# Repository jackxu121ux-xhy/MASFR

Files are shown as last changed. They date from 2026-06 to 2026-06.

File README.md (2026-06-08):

# MASFR: Multimodal Adhesion, Sliding, and Flying Robot

This repository collects replication materials for MASFR, a bioinspired multimodal robot that combines aerial flight with adhesion-assisted surface crawling. MASFR uses distributed micro-setae suction feet inspired by net-winged midge larvae, pressure-regulated adhesion-sliding gaits, and a multi-weighted probabilistic roadmap planner (MW-PRM) for structured multimodal path generation.

The repository is organized to support manuscript review and replication. It includes the MW-PRM planner code and example point-cloud scenes, ROS 2 control software, STM32 crawler firmware, figure-level raw data, representative CAD/STL/STEP files, and an annotated video of successful and representative failed slope-perching trials.

## Manuscript Summary

Flying-perching robots can save energy by attaching to surfaces, but many existing systems must repeatedly take off, realign, and perch when they need to change position after landing. MASFR addresses this limitation by combining flight with controllable adhesion-sliding on surfaces.

The robot is built around four articulated adhesion-sliding legs mounted on a quadrotor platform. Each leg uses a Distributed Micro-setae Sucker (DMS), whose pressure-regulated contact state can switch between high-adhesion and low-friction sliding. In the manuscript experiments, the DMS provides a friction modulation ratio of 407.5%, reducing wet-state shear stress from 21.6 kPa in adhesion mode to 5.3 kPa in sliding mode. The robot demonstrates forward, lateral, and turning gaits through alternating adhesion and sliding phases.

MASFR also includes a lightweight closed-loop crawling controller that uses heading and lateral path errors to generate turning and forward commands for surface trajectory tracking. In robot-level tests, MASFR crawled on a 40 degree inclined surface against 1.5 m/s flow while carrying a 2 kg payload. The reported climbing power consumption was 21.7 W, about 2.3% of flight power under the tested condition.

For mission-level autonomy in known or pre-mapped environments, the project uses MW-PRM. The planner samples aerial, ground, and adhesive-surface nodes from geometric or point-cloud maps, constructs feasible flight, crawling, and adhesive-surface edges, and runs weighted A* over a hybrid graph. The cost model balances energy, traversal time, and mode-switching penalties. Indoor experiments show optimized multimodal trajectories that reduce energy consumption by 31.7% and improve positioning precision by 58.5% compared with single-mode flight.

Outdoor demonstrations on frozen lakeshores, rough pavement, inclined glass roofs, and narrow beam structures validate mechanical feasibility and environmental adaptability. These outdoor tests were pilot-controlled demonstrations rather than online SLAM-based autonomous navigation.

## Repository Layout

```text
MASFR/
|-- algorithms/
|   `-- mw_prm/                         # MW-PRM planner code and examples
|-- cad/                                # CAD, STL, and STEP geometry
|   |-- Crawling System/
|   |-- DMS_sucker/
|   `-- Leg_Module/
|-- multimodal control/                 # ROS 2 control stack and embedded crawling firmware
|   |-- crawling/
|   |   `-- program_stm/                # STM32 crawler control-board firmware
|   `-- masfr_ros2_ws/                  # ROS 2 workspace for MASFR execution
|-- raw data/                           # Figure-level Excel source data
|   |-- Fig.3/
|   |-- Fig.5/
|   `-- Fig.7/
`-- videos/
    `-- Successful and Failed Cases of Slope Perchings .mp4
```

## MW-PRM Algorithm Module

The planner code is provided in `algorithms/mw_prm/`. It supports two environment backends:

- analytic obstacle scenes from Python parameter files;
- point-cloud scenes from `.pcd` or `.ply` files using Open3D, KD-tree collision checking, and 2.5D height-map constraints.

The planner builds a multimodal graph with ground/surface crawling nodes and aerial nodes. Edges are assigned locomotion-mode costs and switching penalties, then searched with A* to produce mode-labeled paths.

### Environment Setup

From the repository root:

```bash
cd algorithms/mw_prm
conda env create -f environment.yml
conda activate mmprm
```

If Conda is unavailable, use Python 3.9+ and install the scientific stack manually. On Python 3.12, `open3d==0.18.0` may not provide wheels on Windows; `open3d==0.19.0` was used successfully for the local smoke test.

### Smoke Test

```bash
cd algorithms/mw_prm
python main_pcd.py --yml yml/pcd/synth_parameters_obstacles.yml --no-vis
```

A successful run loads the synthetic point cloud, samples PRM nodes, connects feasible edges, runs multimodal A*, reports path waypoints and path length, then exits without opening the Open3D viewer because `--no-vis` is enabled.

## ROS 2 Control Software And STM32 Firmware

The execution software is organized under `multimodal control/`.

- `multimodal control/masfr_ros2_ws/` is the MASFR ROS 2 workspace. It contains packages for PX4 offboard control, crawler serial control, TCP motion-capture input, VINS-compatible camera/IMU bridging, launch orchestration, and multimodal mission coordination.
- `multimodal control/crawling/program_stm/` contains the STM32F405 firmware for the crawler control board. It receives serial command packets from the ROS 2 crawling client and drives the solenoid valves, pump output, servo/actuator initialization, and staged gait routines.
- `multimodal control/crawling/` contains crawling-control notes and embedded firmware materials for adhesion-sliding locomotion.

Because the control directory name contains a space, quote it in shell commands:

```bash
cd "multimodal control/masfr_ros2_ws"
source /opt/ros/<ros2-distro>/setup.bash
colcon build --symlink-install
```

## CAD, Raw Data, And Videos

The repository includes releasable supporting materials:

- `cad/` contains STEP/STL files for the crawling system layout, DMS sucker parts, and front/hind leg modules.
- `raw data/` contains Excel source data for Fig.3, Fig.5, and Fig.7.
- `videos/` contains the annotated slope-perching success and failure case video.

See the README files in each directory for file-level indexes.

## Data and Materials Availability

The manuscript states that the main data are available in the main text or supplementary materials. This repository includes source data tables supporting the reported adhesion, friction, locomotion, and multimodal robot-level results, organized by manuscript figure.

The repository also includes control software, STM32 crawler firmware, representative CAD/STL/STEP files, and an annotated video of successful and representative failed slope-perching trials. Additional hardware files may be made available from the corresponding authors upon reasonable request.

## Current Scope and Limitations

The included MW-PRM implementation assumes known or pre-mapped static environments and generates mode-labeled trajectories before execution. It does not yet implement online SLAM or dynamic global replanning. The suction system described in the manuscript currently uses calibrated open-loop pressure regulation; embedded pressure or tactile feedback is a planned extension. Dynamic perching tests in the manuscript showed reliable landing on planar inclined acrylic surfaces up to about 40 degrees under the tested landing conditions.

## Citation

Citation information will be added after publication or preprint release. For questions about the manuscript or hardware materials, please contact the corresponding authors listed in the manuscript.

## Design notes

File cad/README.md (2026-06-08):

# CAD and Design Files

This directory contains releasable CAD, STL, and STEP geometry for the MASFR hardware.

## Contents

- `Crawling System/Crawling System Layout.STEP` - assembly-level crawling system layout.
- `DMS_sucker/DMS Sucker - Distributed micro spines.STL` - distributed micro-spine component for the DMS sucker.
- `DMS_sucker/DMS Sucker - Main body.STL` - main DMS sucker body.
- `DMS_sucker/DMS Sucker - Soft holder.STL` - soft holder component.
- `DMS_sucker/DMS Sucker - Soft Lips.STL` - soft lip component.
- `Leg_Module/Front Leg.STEP` - front leg module geometry.
- `Leg_Module/Hind Leg.STEP` - hind leg module geometry.

## Notes

File names are kept descriptive so that manuscript readers can identify the crawling layout, DMS sucker parts, and leg-module CAD without additional lookup tables. Check dimensions and manufacturing tolerances before using these files for fabrication.

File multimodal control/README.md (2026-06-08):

# Multimodal Control

This directory collects the MASFR execution software and embedded crawling firmware.

## Contents

- `masfr_ros2_ws/` - ROS 2 workspace for PX4 offboard control, crawler serial control, motion-capture feedback, VINS sensor bridging, launch orchestration, and multimodal mission coordination.
- `crawling/program_stm/` - STM32F405 firmware for the crawler control board. It receives serial packets from the ROS 2 crawling client and drives actuator, solenoid, pump, initialization, and gait logic.
- `crawling/README.md` - crawling-control index and hardware safety notes.

## Usage Notes

The ROS 2 workspace keeps the high-level execution nodes. The STM32 firmware in `crawling/program_stm/` provides the low-level actuator, solenoid, pump, and gait logic used by the crawler. The two layers communicate through the serial protocol documented in the `robot_crawl` and `program_stm` README files.

Because this path contains a space, shell examples should quote it:

```bash
cd "multimodal control/masfr_ros2_ws"
```

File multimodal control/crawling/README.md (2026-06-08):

# Crawling Control

This directory contains MASFR crawling-control materials for adhesion-sliding locomotion.

## Contents

- `program_stm/` - STM32F405 firmware for the crawler control board. It receives serial commands, drives solenoid valves and pump outputs, and executes staged gait routines.
- Parameter and notes files may be added here for gait timing tables, pressure/vacuum timing, servo command settings, and trajectory-tracking gains.

## ROS 2 Integration

The high-level ROS 2 crawler package lives in `../masfr_ros2_ws/src/robot_crawl/`. It sends packed serial commands to the STM32 firmware over the configured serial device, typically `/dev/ttyAMA1` at 115200 baud.

The multimodal mission package in `../masfr_ros2_ws/src/multimodal_motion/` can also dispatch crawling segments using motion-capture feedback and the same serial command format.

Before running on hardware, verify the serial device path, actuator wiring, pump/valve mapping, and emergency stop procedure.

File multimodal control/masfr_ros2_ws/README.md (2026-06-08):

# MASFR ROS 2 Workspace

This workspace contains the ROS 2 software used to run and integrate MASFR flight, adhesion-sliding crawling, motion-capture feedback, visual-inertial sensor bridging, and multimodal mission execution.

The ROS 2 package names and executable names are preserved from the source code. The workspace directory was renamed from the uploaded project name to `masfr_ros2_ws` so that the repository layout reflects the MASFR control stack.

## Layout

- `src/` - ROS 2 packages and external PX4/VRPN dependencies.
- `build/`, `install/`, and `log/` - generated by `colcon build` and not required as source files.

## MASFR Packages

- [multimodal_motion](src/multimodal_motion/README.md) - mission coordinator for alternating flight and crawling segments, including `manipulation`, `node_crawling`, and `node_px4`.
- [robot_crawl](src/robot_crawl/Readme.md) - crawler teleoperation and motion-capture-based trajectory following. It sends serial packets to the STM32 crawling firmware under `../crawling/program_stm/`.
- [px4_offboard_control](src/px4_offboard_control/README.md) - PX4 offboard control examples and mission execution with optional serial coordination.
- [mocap_receiver](src/mocap_receiver/README.md) - TCP motion-capture receiver that republishes pose data to ROS 2 and PX4-compatible odometry topics.
- [sensor_to_vins](src/sensor_to_vins/README.md) - stereo image and PX4 IMU bridge for VINS-compatible topics.
- [launch_file](src/launch_file/README.md) - launch descriptions for starting the multimodal motion stack.

## External Packages

- [px4_msgs](src/px4_msgs/README.md) - PX4 uORB-equivalent ROS 2 message definitions.
- [px4_ros_com](src/px4_ros_com/README.md) - PX4 ROS 2 communication examples and frame conversion utilities.
- `px4-ros2-interface-lib/` - PX4 ROS 2 interface library and examples.
- [vrpn_client_ros](src/vrpn_client_ros/README.md) - ROS 2 VRPN client fork used when OptiTrack/VRPN pose streaming is required.

## Build

From the MASFR repository root:

```bash
cd "multimodal control/masfr_ros2_ws"
source /opt/ros/<ros2-distro>/setup.bash
colcon build --symlink-install
source install/setup.bash
```

Build a selected package during development:

```bash
colcon build --packages-select multimodal_motion
```

## Run Examples

```bash
ros2 run px4_offboard_control offboard_control
ros2 run robot_crawl crawl_from_rc
ros2 launch launch_file multimodal_motion.launch.py
```

See the package README files for exact topics, launch assumptions, and hardware requirements.

## Hardware And Configuration Notes

Several nodes contain machine-specific defaults that should be checked before hardware use:

- serial devices such as `/dev/ttyAMA1` and `/dev/ttyAMA2`;
- motion-capture host and port settings;
- CSV trajectory paths used by multimodal mission scripts;
- camera index and stereo frame dimensions used by `sensor_to_vins`.

Convert these values to ROS parameters or environment-specific launch arguments before using the workspace outside the original experiment setup.

## Safety

This workspace can command a PX4 aircraft and a crawling robot through serial links. Test in simulation or a restrained bench setup first, verify the serial device mapping, and keep an emergency stop path available before running motion nodes on hardware.

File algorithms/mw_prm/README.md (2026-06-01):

# MW-PRM — Multi-Modal PRM (MMPRM)

Probabilistic Roadmap (PRM) path planning with **multiple locomotion modes**
(ground walking plus aerial / climbing). This repository provides two
interchangeable scene backends:

- **Analytic** — Convex polyhedron obstacles from `utils/parameters*.py`
  (legacy `main.py` + Matplotlib).
- **Point cloud** — `.pcd` / `.ply` scans with KD-tree collision checking and a
  2.5D heightmap barrier (`main_pcd.py` + Open3D).

The same multi-modal A\* search and B-spline smoothing run in both settings;
only the collision checker is swapped via dependency injection.

**Stack:** Python 3.9+ (3.10 in `environment.yml`), NumPy, SciPy, Open3D,
Matplotlib, NetworkX, scikit-learn, PyYAML (optional `rerun-sdk`).

---

## Repository layout

```text
MW-PRM/
├── main.py                    # Analytic obstacles + Matplotlib demo
├── main_pcd.py                # Point-cloud / Open3D demo (CLI + optional YAML)
├── synth_pcd.py               # Synthetic .pcd from analytic obstacles
├── visualize_pcd.py           # Standalone point cloud viewer
├── plot_csv.py                # Plot paths from CSV
├── convert_mesh_to_zup.py     # Mesh axis utilities (e.g. ICL-NUIM → z-up)
├── environment.yml            # Conda environment (`mmprm`)
├── run_from_yml.sh            # Example: run `main_pcd.py` from a YAML preset
├── run_visualize_from_yml.sh
├── yml/
│   ├── pcd/                   # Planner YAML presets
│   └── visualize/             # Visualization presets
├── pointcloude/               # Sample .pcd inputs (dirname spelling is historical)
├── datasets/                  # Example meshes / scenes (e.g. Stanford Bunny)
└── utils/
    ├── env_pointcloud.py      # PCD pipeline, KD-tree + heightmap checker
    ├── graph.py               # Env-agnostic PRM (injected collision checker)
    ├── path_planning.py       # Multi-modal A\* and B-spline smoothing
    ├── parameters.py          # Large analytic scene
    ├── parameters_test.py     # Small analytic test scene
    └── plotting.py            # Matplotlib helpers (legacy)
```

---

## Environment setup

### Option A — Conda from `environment.yml` (recommended)

```bash
conda env create -f environment.yml
conda activate mmprm
```

If conda channel access is flaky, retry with a mirror:

```bash
conda config --add channels https://mirrors.tuna.tsinghua.edu.cn/anaconda/cloud/conda-forge/
conda config --set show_channel_urls yes
conda env create -f environment.yml
```

### Option B — Plain pip into any Python ≥ 3.9

```bash
pip install -U \
    numpy scipy matplotlib pandas networkx tqdm scikit-learn \
    open3d==0.18.0
# optional, for the alternative renderer
pip install rerun-sdk==0.17.0 PyYAML
```

Use a domestic PyPI mirror with `-i https://pypi.tuna.tsinghua.edu.cn/simple`
if needed.

### Option C — Reuse an existing env

Any environment that already has `open3d>=0.18` plus the standard
scientific stack (`numpy`, `scipy`, `matplotlib`, `pandas`, `networkx`,
`scikit-learn`) is fine. Activate it and skip to **Quick start**.

### Dependencies summary

| Package | Version | Used by |
|---|---|---|
| `python` | ≥ 3.9 (3.10 in `environment.yml`) | everything |
| `numpy` | 1.26.x | everything |
| `scipy` | 1.13.x | KD-tree, B-spline |
| `open3d` | 0.18.0 (or newer) | PCD I/O, KD-tree, 3D viewer |
| `matplotlib` | 3.8.x | legacy `main.py` viewer |
| `pandas` | 2.2.x | `plot_csv.py` |
| `networkx` | 3.2.x | available for graph utilities |
| `scikit-learn` | latest | downsampling, optional |
| `PyYAML` | ≥ 6.0 | `main_pcd.py --yml`, YAML presets |
| `tqdm` | latest | progress bars |
| `rerun-sdk` | 0.17.0 (optional) | alternative renderer |

---

## Quick start

### Legacy analytic-obstacle demo

```bash
python main.py
```

Pops a matplotlib window with the obstacles, PRM samples and the planned
path. Parameters are taken from `utils/parameters_test.py::get_parameters`.

### Point-cloud demo (Open3D)

Run from a YAML preset:

```bash
./run_from_yml.sh
# or: python main_pcd.py --yml yml/pcd/synth_parameters_test_connect_obstacles.yml
```

A real scan:

```bash
python main_pcd.py --pcd pointcloude/scans_e.pcd
```

A synthetic cloud built from the analytic test obstacles, with a known
start / goal:

```bash
# 1) generate the synthetic .pcd  (only needed once)
python synth_pcd.py --params parameters_test --layer real_obstacles \
    --out pointcloude/synth_parameters_test_real_obstacles.pcd

# 2) run the planner
python main_pcd.py \
    --pcd pointcloude/synth_parameters_test_real_obstacles.pcd \
    --voxel 0.3 --r-safe 0.45 --rmax 4.0 \
    --num-ground 1200 --num-surface 600 --num-aerial 800 \
    --max-surface-z 15 \
    --start -24 -5 0 --end 15.5 6.5 11 \
    --wg 1 --wf 5 --e-factor 0.1 \
    --smoothing 5 --lift-epsilon 1.0
```

Press `H` in the Open3D window for keyboard shortcuts; `Q` to close.

### Synthetic PCD generator

Render the analytic obstacles into a binary PCD (with intensity, normals,
curvature) so the PCD pipeline can be unit-tested:

```bash
# big scene from parameters.py
python synth_pcd.py --params parameters --out pointcloude/synth_params.pcd

# small test scene, expanded obstacles
python synth_pcd.py --params parameters_test --layer expand_obstacles \
    --out pointcloude/synth_test_expand.pcd

# add some noise + view immediately
python synth_pcd.py --params parameters --density 80 --noise 0.05 --vis
```

### Point cloud inspector

```bash
# default (height) coloring
python visualize_pcd.py --pcd pointcloude/scans_e.pcd

# color by intensity / show normals as hairs
python visualize_pcd.py --pcd pointcloude/scans_e.pcd --color intensity
python visualize_pcd.py --pcd pointcloude/scans_e.pcd --color normal --show-normals

# compare three scans side-by-side
python visualize_pcd.py --compare pointcloude/scans_e.pcd \
                                  pointcloude/scans_q.pcd \
                                  pointcloude/scans_w.pcd

# downsample + denoise + print stats only
python visualize_pcd.py --pcd pointcloude/scans_e.pcd \
    --voxel 0.1 --denoise --no-vis
```

---

## `main_pcd.py` CLI reference

### Point-cloud preprocessing

| Flag | Default | Meaning |
|---|---|---|
| `--pcd PATH` | `pointcloude/scans_e.pcd` | input `.pcd` file |
| `--voxel FLOAT` | `0.2` | voxel down-sample size (m) |
| `--r-safe FLOAT` | `0.4` | collision safety radius (m) |
| `--ground-thresh FLOAT` | `0.15` | RANSAC ground-plane distance threshold (m) |
| `--ground-clearance FLOAT` | `0.3` | exclude `\|z\| < this` from the obstacle cloud |
| `--max-surface-z FLOAT` | `18.0` | cut walkable surfaces above this height |
| `--max-slope-deg FLOAT` | `50.0` | max slope considered walkable |
| `--surface-lift FLOAT` | `None` | optional lift for walkable-surface samples; by default samples stay directly on the surface and that surface is carved out of the 3D inflated obstacle cloud |
| `--walkable-edge-margin FLOAT` | `r_safe` | keep this XY boundary band of each walkable surface inflated, so samples are only placed on the safe interior |

### PRM graph

| Flag | Default | Meaning |
|---|---|---|
| `--rmax FLOAT` | `4.0` | PRM connection radius (m) |
| `--num-ground INT` | `600` | # ground PRM nodes |
| `--num-surface INT` | `400` | # walkable-surface PRM nodes |
| `--num-aerial INT` | `400` | # aerial PRM nodes |
| `--seed INT` | `0` | RNG seed |
| `--start X Y Z` | auto | start point; if omitted, picked from samples |
| `--end X Y Z` | auto | goal point; if omitted, picked from samples |

### Multi-modal A\* cost model

| Flag | Default | Meaning |
|---|---|---|
| `--wg FLOAT` | `1.0` | ground-walking cost per metre |
| `--wf FLOAT` | `5.0` | aerial / climbing cost per metre |
| `--e-factor FLOAT` | `0.1` | mode-switch penalty as a fraction of `wg` |

### Path smoothing

| Flag | Default | Meaning |
|---|---|---|
| `--smoothing FLOAT` | `5.0` | B-spline smoothing factor |
| `--spline-degree INT` | `3` | B-spline degree (2..5) |
| `--lift-epsilon FLOAT` | `1.0` | vertical lift (m) of virtual control points near take-off / landing on `wf` segments |

### Visualization

| Flag | Default | Meaning |
|---|---|---|
| `--no-vis` | off | run the planner but skip the Open3D window (CI-friendly) |
| `--show-prm` | off | overlay PRM ground edges |
| `--no-samples` | off | hide PRM sample points |
| `--bg {dark,light}` | `dark` | window background |
| `--dim-raw FLOAT` | `0.7` | raw cloud dimming factor (1=full color) |
| `--path-radius FLOAT` | auto | path-tube radius (m); auto = 0.5 % of scene extent |
| `--marker-radius FLOAT` | auto | start / goal sphere radius (m); auto = 1.5 % of extent |
| `--point-size FLOAT` | `2.0` | raw cloud point size (px) |

---

## Tuning the planner

Quick rules of thumb:

* `rmax ≈ 4–6 × voxel`, **and** at least 2× the average node spacing.
* `r_safe ≥ 1.5 × voxel`, otherwise voxel quantisation alone can flag
  edges as in-collision.
* Sample counts scale with the area / volume that needs to be covered.
  Increase them when the planner reports `no path found`.
* `wf / wg` is the "1 m of flight equals N m of walking" ratio.
  Increase `wf` (or `e-factor`) to favour walking; decrease to fly more.
* `lift-epsilon` controls how vertical take-off / landing curves look,
  without changing the planned (collision-checked) waypoints.

If the planner cannot find a path, the most useful first debug step is
`--show-prm`: it overlays the ground edges so you can spot disconnected
islands.

---

## Design notes

### Environment-agnostic graph builder

`utils/graph.py::connect_nearby_nodes` only needs a callable with the
signature `collision_checker(p1, p2) -> bool`. Two adapters are provided:

* `make_polyhedron_collision_checker(params)` — analytic convex polyhedra
  (used by the legacy `main.py`).
* `utils.env_pointcloud.PointCloudCollisionChecker` — point-cloud KD-tree
  with 2.5D heightmap barrier (used by `main_pcd.py`).

### 2.5D heightmap barrier

In addition to the standard 3D KD-tree distance check, the point-cloud
checker keeps a per-xy-cell maximum-z map ("local roof height"). A query
point `(x, y, z)` counts as in-collision when `z < heightmap(x, y) − r_safe`,
i.e. it sits *under* an obstacle's local roof. This catches two
otherwise-undetected cases:

* ground edges that diagonally cross an obstacle's xy footprint at z=0
  after `--ground-clearance` has removed the lower wall band;
* aerial samples that fall *inside* a closed obstacle volume.

### Multi-modal cost preserved

`generate_nodes_pointcloud` returns the samples and an `is_surface`
boolean mask. `connect_nearby_nodes` uses it to assign edge weights
exactly like the original implementation:

* ground ↔ ground: `wg`
* surface ↔ surface: `wg`
* aerial ↔ * : `wf`
* mixed: `[wf, e]` with mode-switch penalty `e = wg · e_factor`

### A\* untouched

`utils/path_planning.py::astar` is unchanged from the analytic version;
the multi-modal heuristic and B-spline smoother work identically across
both backends.

---

## Troubleshooting

| Symptom | Likely cause | Fix |
|---|---|---|
| `no path found` | PRM disconnected | larger `--rmax`, more samples, `--show-prm` to visualise |
| start / goal stuck inside a wall | snapped to the wrong free node | pass an explicit `--start / --end` away from obstacles |
| path visibly clips an obstacle | scan noise has filled the obstacle interior | increase `--ground-clearance`; verify with `visualize_pcd.py` |
| `_tkinter.TclError` on a headless box | matplotlib trying to open a GUI | run `main.py` only in a desktop session, or use `main_pcd.py` with `--no-vis` |
| Open3D window is empty / black | bad GL drivers | upgrade graphics drivers, or run `--no-vis` and inspect the textual output |
| `ImportError: open3d` | env not activated | `conda activate mmprm` (or your env), or reinstall per **Environment setup** |

---

## Reproducing the multi-modal demo

The combination below reproduces the figure used during development
(takes ~20 s on a recent CPU):

```bash
python synth_pcd.py --params parameters_test --layer real_obstacles \
    --out pointcloude/synth_parameters_test_real_obstacles.pcd

python main_pcd.py \
    --pcd pointcloude/synth_parameters_test_real_obstacles.pcd \
    --voxel 0.3 --r-safe 0.45 --rmax 4.0 \
    --num-ground 1200 --num-surface 600 --num-aerial 800 \
    --max-surface-z 15 \
    --start -24 -5 0 --end 15.5 6.5 11 \
    --wg 1 --wf 5 --e-factor 0.1 \
    --smoothing 5 --lift-epsilon 1.0 \
    --bg dark --dim-raw 0.55 --no-samples
```

Expected output:

```
[1/5] loading pointcloude/synth_parameters_test_real_obstacles.pcd ...
      raw points    :    42192
      ground points :    12347
      non-ground    :    29174
[2/5] sampling PRM nodes ...
      ground / surface / aerial = 1200 / 600 / 800
[3/5] connecting PRM edges (R=4.0, N=2602) ...
      total edges : ~48000
[4/5] running multi-modal A* ...
      path waypoints : ~22-25
      path length    : ~63 m
[5/5] preparing visualization ...
```

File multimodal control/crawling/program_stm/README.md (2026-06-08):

# program_stm

STM32F405-based firmware project for the crawler control board.

This project provides the low-level firmware that drives the robot's actuators and gait logic. It is stored under the MASFR crawling-control materials and is intended to work together with `robotSerial.py` from the ROS 2 `robot_crawl` package, which sends commands over UART from a keyboard or ROS 2 node to the MCU.

## What it does

- Receives 8-byte serial commands on `USART1` at 115200 baud.
- Switches the LED, solenoid valves, and pump output.
- Executes crawler motion routines such as forward, backward, left, right, and continuous forward walking.
- Initializes the servo/actuator state at startup and keeps the robot in a known pose before motion commands are processed.

## How it works with `robotSerial.py`

`robotSerial.py` is the operator-side client. It packs control commands and writes them to the serial port. The STM32 firmware receives those packets in `Core/Src/main.c`, parses them in the UART receive callback, and calls the motion helpers in `Hardware/robotMotion/robotMotion.c`.

Typical command groups are:

- `0x01` - LED toggle
- `0x02` - solenoid valve toggle
- `0x03` - pump toggle
- `0x7F` - gait command

For gait commands, the packet carries:

- `cmd_id` - motion type
- `param1` - first stepping side
- `param2` - step scale / division factor

The keyboard client maps keys like `w/q/s/e`, `a/d`, `1-4`, `0`, and `l` to those packet types.

## Main motion routines

- `robotOneStepForward()` - single forward step
- `robotOneStepBackward()` - single backward step
- `robotOneStepLeft()` - single lateral step to the left
- `robotOneStepRight()` - single lateral step to the right
- `robotContinuousForward()` - repeated forward stepping until a stop flag is received

These routines coordinate the solenoid valves and servo positions in a staged sequence.

## Directory overview

- `Core/` - application source, startup code, interrupt handlers, and MCU initialization.
- `Hardware/` - custom hardware drivers and motion code.
- `Drivers/` - STM32 HAL and CMSIS vendor code.
- `control_circuit.ioc` - CubeMX project configuration.
- `MDK-ARM/` - Keil MDK project files.

## Build notes

The project was generated for STM32CubeMX and Keil MDK. A typical workflow is:

1. Open `control_circuit.ioc` in CubeMX if you need to regenerate code.
2. Open `MDK-ARM/control_circuit.uvprojx` in Keil MDK.
3. Build the target and flash the generated firmware to the board.

## File policy for open source

The repository keeps source and project configuration files, but excludes local IDE settings, debug views, and build outputs. Those files are either ignored or stored in `_local_ignored/` for local recovery.

## Safety

- Verify the correct serial device before connecting hardware.
- Confirm the board is powered and the actuator wiring matches the firmware pins.
- Test on a bench or with power cut-off ready before running motion commands.

## License

See the repository root license and any vendor license files included under `Drivers/`.

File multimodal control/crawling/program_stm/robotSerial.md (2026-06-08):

# robotSerial.py

Purpose
- Keyboard teleoperation helper that sends packed binary commands over a serial port to robot hardware (solenoids, pump, step motions, LED).

Dependencies
- Python 3
- pyserial
- pynput

Install
```bash
pip install pyserial pynput
```

Default serial settings
- Device: `/dev/ttyAMA1`
- Baudrate: `115200`
- Message format: `struct.pack('bbbbf', cmd_type, cmd_id, param1, param2, param3)`

Run
```bash
python robotSerial.py
```
On Windows change the device string in the script to a COM port (for example `COM3`).

Keyboard mapping
- `l` — LED toggle (raw bytes)
- `w` — one step forward (left-first)
- `q` — one step forward (right-first)
- `s` — one step backward (left-first)
- `e` — one step backward (right-first)
- `a` — step left
- `d` — step right
- `1`–`4` — toggle solenoid valve channel 1..4
- `7` — trigger channels 1..4 (all)
- `8` — trigger channels 1 and 2
- `9` — trigger channels 3 and 4
- `0` — pump switch
- `Esc` — exit

Notes
- Some `struct.pack` calls use explicit little-endian format (`'<bbbbf'`) in the code — ensure the receiving firmware expects the same endianness.
- The script opens the serial port immediately; change the hardcoded string to parameterize the port for safer use.

Safety checklist
- Verify the correct serial device and baudrate before running.
- Test with hardware powered off or use a serial monitor to inspect bytes first.
- Have a physical emergency stop or power cutoff available.

Suggested improvements
- Add CLI args or environment variable to configure `serial_port` and `baudrate`.
- Add a `--dry-run` mode that prints packed bytes instead of writing to serial.
- Add logging and confirmation prompts for high-risk commands (pump/solenoids).

License
- This file follows the same licensing and distribution rules as the repository it belongs to.

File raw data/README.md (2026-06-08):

# Raw Data

This directory contains figure-level Excel source data for the MASFR manuscript.

## Contents

### Fig.3

- `Fig.3/Fig.3C.xlsx`
- `Fig.3/Fig.3D.xlsx`
- `Fig.3/Fig.3E.xlsx`
- `Fig.3/Fig.3F.xlsx`
- `Fig.3/Fig.3G.xlsx`

### Fig.5

- `Fig.5/Fig.5B.xlsx`
- `Fig.5/Fig.5C.xlsx`
- `Fig.5/Fig.5D.xlsx`
- `Fig.5/Fig.5E.xlsx`
- `Fig.5/Fig.5H.xlsx`
- `Fig.5/Fig.5I.xlsx`

### Fig.7

- `Fig.7/Fig.7B and 7C.xlsx`

## Notes

The workbook names follow the corresponding manuscript figure panels. Preserve the original sheets, units, and trial labels when adding or revising data files so that manuscript figures remain traceable to source measurements.

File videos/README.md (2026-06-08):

# Videos

This directory contains annotated videos for MASFR demonstrations and representative trial outcomes.

## Contents

- `Successful and Failed Cases of Slope Perchings .mp4` - annotated video showing successful and failed slope-perching cases.

## Notes

The video file is included as supporting material for manuscript review and replication context. Keep future videos accompanied by a short note describing the scenario, surface, payload, mode sequence, and outcome.

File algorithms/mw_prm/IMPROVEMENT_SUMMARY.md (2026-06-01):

# 可行走表面检测改进方案总结

## 问题回顾

你询问："有没有什么更加科学专业有引用依据的方法来检验可以着陆面，设置着陆面mask"

## 答案总结

是的，有很多更科学、有学术依据的方法。我已经为你准备了：

### 1. 学术综述文档
📄 **[WALKABLE_SURFACE_METHODS.md](WALKABLE_SURFACE_METHODS.md)**

包含：
- 当前实现的分析和局限性
- 学术界4大类方法的详细介绍
- 每种方法的参考文献（期刊论文、会议论文）
- 工业界实践（Boston Dynamics、ANYmal、NASA JPL）
- 3种改进方案的完整实现代码
- 参数调优指南
- 不同场景的推荐配置

### 2. 可直接使用的改进实现
📄 **[improved_walkable_detection.py](improved_walkable_detection.py)**

提供了3个关键函数：

#### `compute_pca_features()` - PCA特征分析
基于 **Weinmann et al. (2015)** 的方法，计算：
- **平面性** (planarity): 判断是否为平面
- **线性度** (linearity): 判断是否为线性结构
- **球形度** (sphericity): 判断是否为散乱点

#### `compute_local_roughness()` - 粗糙度检测
基于 **Papadakis (2013)** 的地形可通行性分析，计算点到拟合平面的RMS距离。

#### `enhanced_walkable_surface_mask()` - 增强检测
综合多个几何特征：
- ✅ 法向量角度（原有）
- ✅ 高度范围（原有）
- ✅ **PCA平面性**（新增）
- ✅ **局部粗糙度**（新增）
- ✅ 多半径法向量（原有，处理薄表面）

#### `filter_by_connected_area_improved()` - 改进的连通性过滤
修复原始实现的问题：
- ✅ 使用8-连通而不是4-连通
- ✅ 基于面积而不是XY跨度的AND
- ✅ 自动确保cell_xy不会太小

## 主要学术参考文献

### 综述
1. **Papadakis, P. (2013)**. "Terrain traversability analysis methods for unmanned ground vehicles: A survey". *Engineering Applications of Artificial Intelligence*, 26(4), 1373-1385.

2. **Borges, P., et al. (2015)**. "A survey on terrain traversability analysis for autonomous ground vehicles". *Unmanned Systems*, 3(02), 125-146.

### 几何方法
3. **Weinmann, M., et al. (2015)**. "Semantic point cloud interpretation based on optimal neighborhoods, relevant features and efficient classifiers". *ISPRS Journal of Photogrammetry and Remote Sensing*, 105, 286-304.

### 高程图方法
4. **Fankhauser, P., & Hutter, M. (2018)**. "A Universal Grid Map Library: Implementation and Use Case for Rough Terrain Navigation". *Robot Operating System (ROS)*.

5. **Fankhauser, P., et al. (2018)**. "Probabilistic terrain mapping for mobile robots with uncertain localization". *IEEE Robotics and Automation Letters*, 3(4), 3019-3026.

### 工业实践
- **ANYbotics** (ANYmal四足机器人): elevation_mapping + grid_map
- **Boston Dynamics**: 多层次地形表示 + 实时更新
- **NASA JPL** (火星车): GESTALT系统

## 如何使用

### 方案1：快速测试改进方法

```bash
# 测试改进的检测方法
python improved_walkable_detection.py pointcloude/synth_parameters_test_real_obstacles.pcd
```

### 方案2：集成到现有代码

在 `utils/env_pointcloud.py` 中替换 `walkable_surface_mask` 函数：

```python
# 导入改进的实现
from improved_walkable_detection import enhanced_walkable_surface_mask

# 在 build_environment 函数中使用
walk_mask = enhanced_walkable_surface_mask(
    non_ground,
    max_slope_deg=walkable_max_slope_deg,
    max_roughness=0.1,  # 新参数
    min_planarity=0.65,  # 新参数
    search_radius=float(voxel_size) * 2.0,  # 新参数
    z_min_above_ground=float(z_min_walkable_surface),
    max_height=walkable_max_height,
    normal_radii=walkable_normal_radii,
)
```

### 方案3：添加新的YAML参数

在配置文件中添加：

```yaml
# 增强的可行走表面检测参数
walkable_max_roughness: 0.1      # 最大粗糙度（米）
walkable_min_planarity: 0.65     # 最小平面性（0-1）
walkable_pca_radius: 0.6         # PCA搜索半径（米，通常为2×voxel_size）

# 改进的连通性过滤
walkable_min_area: 0.5           # 最小面积（平方米）而不是XY跨度
walkable_use_8_connected: true   # 使用8-连通而不是4-连通
```

## 推荐的实施路径

### 阶段1：立即修复（已完成）
✅ 修复参数配置问题
- `walkable_min_landing_xy: 0.0` 或合理值
- `walkable_cluster_cell_xy >= voxel_size`

### 阶段2：添加基础改进（1-2天）
建议优先实现：
1. **粗糙度检测** - 过滤粗糙表面
2. **改进连通性过滤** - 使用8-连通 + 面积判断

这两个改进：
- 实现简单
- 计算开销小
- 效果明显
- 不破坏现有接口

### 阶段3：完整增强（1-2周）
实现完整的 `enhanced_walkable_surface_mask`：
- PCA平面性检测
- 多特征融合
- 完整的参数配置

### 阶段4：高级方法（可选，1-2月）
如果需要更高的性能：
- 实现基于高程图的方法
- 实现混合方法
- 添加可视化和调试工具

## 不同场景的推荐参数

### 室内场景（办公室、走廊）
```yaml
max_slope_deg: 30.0
max_roughness: 0.08
min_planarity: 0.75
min_area: 0.3
```

### 室外场景（草地、碎石路）
```yaml
max_slope_deg: 45.0
max_roughness: 0.15
min_planarity: 0.60
min_area: 0.5
```

### 工业场景（仓库、工厂）
```yaml
max_slope_deg: 35.0
max_roughness: 0.10
min_planarity: 0.70
min_area: 0.4
```

## 关键改进点

相比当前实现，改进方法的优势：

| 特性 | 当前实现 | 改进方法 | 学术依据 |
|---|---|---|---|
| 法向量角度 | ✅ | ✅ | 标准方法 |
| 高度过滤 | ✅ | ✅ | 标准方法 |
| 平面性检测 | ❌ | ✅ | Weinmann 2015 |
| 粗糙度检测 | ❌ | ✅ | Papadakis 2013 |
| 连通性算法 | 4-连通 + XY跨度 | 8-连通 + 面积 | 图论标准 |
| 参数鲁棒性 | 低（易出错） | 高（自动检查） | 工程实践 |

## 开源参考实现

如果需要更多参考，可以查看这些开源项目：

1. **ANYbotics elevation_mapping**
   - https://github.com/ANYbotics/elevation_mapping
   - 工业级实现，用于ANYmal四足机器人

2. **grid_map**
   - https://github.com/ANYbotics/grid_map
   - 通用的2.5D地图库

3. **PCL (Point Cloud Library)**
   - https://pointclouds.org/
   - 包含各种点云处理算法

## 总结

你的问题问得很好！当前实现确实可以改进。我提供的方案：

1. ✅ **有学术依据** - 所有方法都有期刊/会议论文支持
2. ✅ **工业验证** - 在实际机器人系统中使用（ANYmal、Boston Dynamics）
3. ✅ **可直接使用** - 提供了完整的实现代码
4. ✅ **向后兼容** - 可以逐步集成，不破坏现有功能
5. ✅ **参数指导** - 提供了不同场景的推荐配置

建议从**粗糙度检测**和**改进连通性过滤**开始，这两个改进实现简单但效果明显。

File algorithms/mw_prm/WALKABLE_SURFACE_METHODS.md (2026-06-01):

# 可行走表面检测方法：学术综述与改进建议

## 当前实现分析

### 现有方法（`utils/env_pointcloud.py`）

当前代码使用的方法：

1. **法向量角度检测** (`walkable_surface_mask`)
   - 估计每个点的法向量
   - 检查法向量与+Z轴的夹角是否 ≤ `max_slope_deg`（默认50°）
   - 使用多个搜索半径（multi-radius OR）来处理薄表面

2. **高度范围过滤**
   - `z_min_above_ground` < z < `max_height`
   - 过滤掉地面和过高的表面

3. **XY平面连通性过滤** (`prune_walk_mask_by_landing_xy_extent`)
   - 基于网格的并查集算法
   - 过滤掉XY方向跨度太小的表面（窗台、栏杆等）

### 问题与局限性

1. **法向量估计不稳定**
   - 对噪声敏感
   - 边缘区域法向量不准确
   - 搜索半径选择影响结果

2. **缺乏几何一致性检查**
   - 没有考虑局部平面拟合质量
   - 没有检查表面粗糙度

3. **连通性算法有缺陷**
   - 参数配置敏感（如前面诊断的问题）
   - 没有考虑高度变化

---

## 学术界方法综述

### 1. 基于地形分析的方法

#### 1.1 Traversability Analysis (可通行性分析)

**经典方法**：
- **论文**: Papadakis, P. (2013). "Terrain traversability analysis methods for unmanned ground vehicles: A survey"
- **方法**: 
  - 局部平面拟合 + 残差分析
  - 坡度、粗糙度、阶梯高度联合评估
  - 使用高程图（elevation map）

**核心指标**：
```python
# 1. 坡度 (Slope)
slope = arctan(sqrt(dz/dx^2 + dz/dy^2))

# 2. 粗糙度 (Roughness) - 点到拟合平面的RMS距离
roughness = sqrt(mean((z_i - z_fitted)^2))

# 3. 阶梯高度 (Step height)
step_height = max(z) - min(z) in local neighborhood

# 4. 曲率 (Curvature)
curvature = eigenvalues of local covariance matrix
```

**引用依据**:
- Papadakis, P. (2013). "Terrain traversability analysis methods for unmanned ground vehicles: A survey". *Engineering Applications of Artificial Intelligence*, 26(4), 1373-1385.

#### 1.2 Elevation Map + Grid-based Analysis

**方法**: 
- 将点云投影到2.5D高程图
- 每个网格单元计算统计特征
- 基于规则或学习的分类器

**优点**:
- 计算效率高
- 易于集成到规划器
- 适合大规模场景

**实现参考**:
- **ANYmal** (ETH Zurich): "Elevation Mapping for Locomotion and Navigation using GPU"
- **论文**: Fankhauser, P., & Hutter, M. (2018). "A Universal Grid Map Library: Implementation and Use Case for Rough Terrain Navigation". *Robot Operating System (ROS)*.

### 2. 基于机器学习的方法

#### 2.1 PointNet-based Classification

**方法**:
- 直接在点云上进行语义分割
- 学习局部几何特征
- 端到端训练

**代表工作**:
- **PointNet++**: Qi, C. R., et al. (2017). "PointNet++: Deep hierarchical feature learning on point sets in a metric space". *NeurIPS*.
- **RandLA-Net**: Hu, Q., et al. (2020). "RandLA-Net: Efficient semantic segmentation of large-scale point clouds". *CVPR*.

**优点**:
- 可以学习复杂的可行走性模式
- 对噪声鲁棒
- 可以处理多种地形类型

**缺点**:
- 需要标注数据
- 计算开销大
- 泛化性能依赖训练数据

#### 2.2 Self-Supervised Learning

**方法**:
- 使用机器人的实际行走数据作为监督信号
- 在线学习可行走性模型

**代表工作**:
- Filitchkin, P., & Byl, K. (2012). "Feature-based terrain classification for LittleDog". *IROS*.
- Wellhausen, L., et al. (2019). "Where should I walk? Predicting terrain properties from images via self-supervised learning". *IEEE Robotics and Automation Letters*.

### 3. 基于几何特征的经典方法

#### 3.1 PCA-based Surface Analysis

**方法**:
- 对局部邻域进行PCA分析
- 使用特征值判断表面类型

**特征值分析**:
```python
# 对局部点集进行PCA
eigenvalues: λ1 >= λ2 >= λ3 (归一化: λ1 + λ2 + λ3 = 1)

# 表面类型判断:
# - 平面: λ3 << λ2 ≈ λ1 (linearity ≈ 0, planarity ≈ 1)
# - 线性: λ2 << λ1, λ3 << λ1 (linearity ≈ 1)
# - 散乱: λ1 ≈ λ2 ≈ λ3 (sphericity ≈ 1)

linearity = (λ1 - λ2) / λ1
planarity = (λ2 - λ3) / λ1
sphericity = λ3 / λ1
```

**可行走性判断**:
- 高planarity + 低sphericity → 可能是可行走表面
- 检查最小特征值对应的特征向量（法向量）与+Z的夹角

**引用依据**:
- Weinmann, M., et al. (2015). "Semantic point cloud interpretation based on optimal neighborhoods, relevant features and efficient classifiers". *ISPRS Journal of Photogrammetry and Remote Sensing*, 105, 286-304.

#### 3.2 RANSAC-based Plane Segmentation

**方法**:
- 使用RANSAC迭代拟合平面
- 评估平面质量（内点数、残差）
- 检查平面方向和大小

**改进版本**:
- **Multi-RANSAC**: 同时拟合多个平面
- **Region Growing**: RANSAC + 区域生长

**引用依据**:
- Schnabel, R., et al. (2007). "Efficient RANSAC for point-cloud shape detection". *Computer Graphics Forum*, 26(2), 214-226.

### 4. 机器人领域的实用方法

#### 4.1 Boston Dynamics / ANYmal 方法

**核心思想**:
- 多层次地形表示
- 实时更新的局部地图
- 基于物理约束的可行走性评估

**关键技术**:
- **Elevation mapping**: 2.5D高程图 + 方差估计
- **Traversability estimation**: 基于坡度、粗糙度、阶梯高度
- **Uncertainty propagation**: 考虑传感器噪声和遮挡

**开源实现**:
- `elevation_mapping` (ROS package by ANYbotics)
- `grid_map` (ROS package by ANYbotics)

**论文**:
- Fankhauser, P., et al. (2018). "Probabilistic terrain mapping for mobile robots with uncertain localization". *IEEE Robotics and Automation Letters*, 3(4), 3019-3026.

#### 4.2 NASA JPL 火星车方法

**GESTALT系统** (Geometric Evaluation of Surface Traversability Applied to Lunar Terrain):
- 多尺度地形分析
- 基于物理模型的可通行性评估
- 考虑车辆几何和动力学约束

**论文**:
- Gorevan, S., et al. (2008). "Rock abrasion tool: Mars Exploration Rover mission". *Journal of Geophysical Research*, 113(E12).
- Goldberg, S. B., et al. (2002). "Stereo vision and rover navigation software for planetary exploration". *IEEE Aerospace Conference*.

---

## 推荐的改进方案

### 方案1：增强的几何特征方法（推荐）

**优点**: 不需要训练数据，计算效率高，可解释性强

#### 实现步骤：

```python
def enhanced_walkable_surface_mask(
    pcd: o3d.geometry.PointCloud,
    max_slope_deg: float = 50.0,
    max_roughness: float = 0.1,  # 米
    min_planarity: float = 0.7,
    search_radius: float = 0.3,
    z_range: Tuple[float, float] = (0.05, 18.0),
) -> np.ndarray:
    """
    基于多个几何特征的可行走表面检测
    
    参考文献:
    - Weinmann et al. (2015) - PCA特征
    - Papadakis (2013) - 地形可通行性分析
    """
    pts = np.asarray(pcd.points)
    n_pts = len(pts)
    
    # 1. 高度过滤
    z_mask = (pts[:, 2] >= z_range[0]) & (pts[:, 2] <= z_range[1])
    
    # 2. 估计法向量（如果没有）
    if not pcd.has_normals():
        pcd.estimate_normals(
            search_param=o3d.geometry.KDTreeSearchParamHybrid(
                radius=search_radius, max_nn=30
            )
        )
        pcd.orient_normals_to_align_with_direction([0, 0, 1])
    
    normals = np.asarray(pcd.normals)
    
    # 3. 坡度检测（法向量与+Z的夹角）
    cos_angle = np.abs(normals @ np.array([0, 0, 1]))
    cos_angle = np.clip(cos_angle, -1, 1)
    slope_angles = np.degrees(np.arccos(cos_angle))
    slope_mask = slope_angles <= max_slope_deg
    
    # 4. PCA特征分析
    tree = o3d.geometry.KDTreeFlann(pcd)
    planarity = np.zeros(n_pts)
    roughness = np.zeros(n_pts)
    
    for i in range(n_pts):
        [k, idx, _] = tree.search_radius_vector_3d(pcd.points[i], search_radius)
        if k < 10:  # 需要足够的邻居点
            continue
        
        neighbors = pts[idx]
        
        # PCA分析
        centroid = neighbors.mean(axis=0)
        centered = neighbors - centroid
        cov = centered.T @ centered / k
        eigenvalues, eigenvectors = np.linalg.eigh(cov)
        
        # 归一化特征值（从小到大）
        eigenvalues = np.sort(eigenvalues)
        if eigenvalues.sum() > 1e-9:
            eigenvalues = eigenvalues / eigenvalues.sum()
        
        # 平面性 = (λ2 - λ3) / λ1
        if eigenvalues[2] > 1e-9:
            planarity[i] = (eigenvalues[1] - eigenvalues[0]) / eigenvalues[2]
        
        # 粗糙度 = 点到拟合平面的RMS距离
        # 拟合平面的法向量是最小特征值对应的特征向量
        normal = eigenvectors[:, 0]  # 最小特征值的特征向量
        distances = np.abs((neighbors - centroid) @ normal)
        roughness[i] = np.sqrt(np.mean(distances ** 2))
    
    planarity_mask = planarity >= min_planarity
    roughness_mask = roughness <= max_roughness
    
    # 5. 综合判断
    walkable_mask = z_mask & slope_mask & planarity_mask & roughness_mask
    
    return walkable_mask
```

**关键改进**:
1. **平面性检测**: 使用PCA特征值判断表面是否为平面
2. **粗糙度检测**: 过滤掉粗糙的表面（碎石、灌木等）
3. **多特征融合**: 综合多个几何特征，提高鲁棒性

### 方案2：基于高程图的方法

**优点**: 计算效率高，适合大规模场景，易于集成

#### 实现步骤：

```python
def elevation_map_walkable_detection(
    pcd: o3d.geometry.PointCloud,
    cell_size: float = 0.2,  # 网格单元大小
    max_slope: float = 0.7,  # tan(35°) ≈ 0.7
    max_roughness: float = 0.15,  # 米
    max_step_height: float = 0.3,  # 米
    min_points_per_cell: int = 5,
) -> Tuple[np.ndarray, np.ndarray]:
    """
    基于2.5D高程图的可行走表面检测
    
    参考文献:
    - Fankhauser & Hutter (2018) - Grid Map Library
    - ANYbotics elevation_mapping
    
    返回:
    - walkable_mask: 每个点的可行走性标记
    - elevation_map: 高程图（用于可视化和规划）
    """
    pts = np.asarray(pcd.points)
    
    # 1. 构建高程图
    x_min, y_min = pts[:, :2].min(axis=0)
    x_max, y_max = pts[:, :2].max(axis=0)
    
    nx = int(np.ceil((x_max - x_min) / cell_size))
    ny = int(np.ceil((y_max - y_min) / cell_size))
    
    # 网格索引
    gx = ((pts[:, 0] - x_min) / cell_size).astype(int)
    gy = ((pts[:, 1] - y_min) / cell_size).astype(int)
    gx = np.clip(gx, 0, nx - 1)
    gy = np.clip(gy, 0, ny - 1)
    
    # 每个网格单元的统计信息
    elevation_map = np.full((nx, ny), np.nan)
    variance_map = np.full((nx, ny), np.nan)
    slope_map = np.full((nx, ny), np.nan)
    roughness_map = np.full((nx, ny), np.nan)
    
    # 计算每个网格单元的统计量
    from collections import defaultdict
    cells = defaultdict(list)
    for i, (ix, iy) in enumerate(zip(gx, gy)):
        cells[(ix, iy)].append(i)
    
    for (ix, iy), indices in cells.items():
        if len(indices) < min_points_per_cell:
            continue
        
        cell_pts = pts[indices]
        z_values = cell_pts[:, 2]
        
        # 高程（均值或中位数）
        elevation_map[ix, iy] = np.median(z_values)
        
        # 方差
        variance_map[ix, iy] = np.var(z_values)
        
        # 粗糙度（标准差）
        roughness_map[ix, iy] = np.std(z_values)
    
    # 2. 计算坡度（使用Sobel算子）
    from scipy.ndimage import sobel
    
    # 填充NaN值（用于梯度计算）
    elevation_filled = elevation_map.copy()
    mask = ~np.isnan(elevation_filled)
    if mask.sum() > 0:
        from scipy.ndimage import distance_transform_edt
        # 简单的最近邻插值
        ind = distance_transform_edt(~mask, return_distances=False, return_indices=True)
        elevation_filled = elevation_filled[tuple(ind)]
    
    # 计算梯度
    grad_x = sobel(elevation_filled, axis=0) / cell_size
    grad_y = sobel(elevation_filled, axis=1) / cell_size
    slope_map = np.sqrt(grad_x**2 + grad_y**2)
    
    # 3. 可行走性判断
    walkable_grid = (
        (slope_map <= max_slope) &
        (roughness_map <= max_roughness) &
        (~np.isnan(elevation_map))
    )
    
    # 4. 将网格结果映射回点
    walkable_mask = np.zeros(len(pts), dtype=bool)
    for i, (ix, iy) in enumerate(zip(gx, gy)):
        if walkable_grid[ix, iy]:
            walkable_mask[i] = True
    
    return walkable_mask, {
        'elevation': elevation_map,
        'slope': slope_map,
        'roughness': roughness_map,
        'walkable': walkable_grid,
        'cell_size': cell_size,
        'origin': (x_min, y_min),
    }
```

### 方案3：混合方法（最佳实践）

结合几何特征和高程图的优点：

```python
def hybrid_walkable_detection(
    pcd: o3d.geometry.PointCloud,
    # 几何特征参数
    max_slope_deg: float = 50.0,
    min_planarity: float = 0.6,
    max_roughness_local: float = 0.1,
    search_radius: float = 0.3,
    # 高程图参数
    cell_size: float = 0.2,
    max_slope_global: float = 0.7,
    max_roughness_global: float = 0.15,
    # 连通性参数
    min_area: float = 0.5,  # 平方米
) -> np.ndarray:
    """
    混合方法：局部几何特征 + 全局高程图 + 连通性分析
    
    优点：
    - 局部特征捕捉细节（边缘、小障碍）
    - 全局特征提供上下文（坡度、连通性）
    - 多层次验证，提高鲁棒性
    """
    # 1. 局部几何特征检测
    local_mask = enhanced_walkable_surface_mask(
        pcd, max_slope_deg, max_roughness_local,
        min_planarity, search_radius
    )
    
    # 2. 全局高程图检测
    global_mask, elevation_info = elevation_map_walkable_detection(
        pcd, cell_size, max_slope_global, max_roughness_global
    )
    
    # 3. 取交集（两种方法都认为可行走）
    combined_mask = local_mask & global_mask
    
    # 4. 连通性过滤（改进版）
    if min_area > 0:
        combined_mask = filter_by_connected_area(
            pcd, combined_mask, min_area, cell_size
        )
    
    return combined_mask

def filter_by_connected_area(
    pcd: o3d.geometry.PointCloud,
    mask: np.ndarray,
    min_area: float,
    cell_size: float,
) -> np.ndarray:
    """
    改进的连通性过滤：基于实际面积而不是XY跨度
    
    修复原始 prune_walk_mask_by_landing_xy_extent 的问题：
    - 使用合理的cell_size（不会太小）
    - 基于面积判断（而不是XY跨度的AND）
    - 考虑3D连通性
    """
    pts = np.asarray(pcd.points)
    walkable_pts = pts[mask]
    
    if len(walkable_pts) == 0:
        return mask
    
    # 投影到XY平面并网格化
    xy = walkable_pts[:, :2]
    xy_min = xy.min(axis=0)
    
    gx = ((xy[:, 0] - xy_min[0]) / cell_size).astype(int)
    gy = ((xy[:, 1] - xy_min[1]) / cell_size).astype(int)
    
    # 构建网格占用图
    from collections import defaultdict
    grid_to_points = defaultdict(list)
    walkable_indices = np.where(mask)[0]
    
    for i, (ix, iy) in enumerate(zip(gx, gy)):
        grid_to_points[(ix, iy)].append(walkable_indices[i])
    
    # 并查集找连通区域
    parent = {cell: cell for cell in grid_to_points}
    
    def find(x):
        if parent[x] != x:
            parent[x] = find(parent[x])
        return parent[x]
    
    def union(a, b):
        ra, rb = find(a), find(b)
        if ra != rb:
            parent[rb] = ra
    
    # 8-连通（而不是4-连通）
    for (cx, cy) in grid_to_points:
        for dx in [-1, 0, 1]:
            for dy in [-1, 0, 1]:
                if dx == 0 and dy == 0:
                    continue
                neighbor = (cx + dx, cy + dy)
                if neighbor in grid_to_points:
                    union((cx, cy), neighbor)
    
    # 计算每个连通区域的面积
    components = defaultdict(list)
    for cell in grid_to_points:
        components[find(cell)].append(cell)
    
    # 过滤小区域
    surviving_mask = np.zeros_like(mask)
    for cells in components.values():
        area = len(cells) * (cell_size ** 2)
        if area >= min_area:
            for cell in cells:
                for idx in grid_to_points[cell]:
                    surviving_mask[idx] = True
    
    return surviving_mask
```

---

## 实施建议

### 短期（立即可用）

1. **修复当前实现的参数问题**（已完成）
   - 设置 `walkable_min_landing_xy = 0` 或合理值
   - 显式设置 `walkable_cluster_cell_xy >= voxel_size`

2. **添加粗糙度检测**
   ```python
   # 在 walkable_surface_mask 中添加
   roughness = compute_local_roughness(non_ground, search_radius)
   roughness_mask = roughness <= max_roughness
   combined_mask &= roughness_mask
   ```

### 中期（1-2周）

3. **实现增强的几何特征方法**（方案1）
   - 添加PCA平面性检测
   - 添加粗糙度检测
   - 保持向后兼容

4. **改进连通性过滤**
   - 使用8-连通而不是4-连通
   - 基于面积而不是XY跨度
   - 自动选择合理的cell_size

### 长期（1-2月）

5. **实现高程图方法**（方案2）
   - 构建2.5D高程图
   - 计算坡度、粗糙度、阶梯高度
   - 提供可视化和调试工具

6. **集成混合方法**（方案3）
   - 结合局部和全局特征
   - 提供多种预设配置
   - 添加自动参数调优

---

## 参数调优指南

### 关键参数及其影响

| 参数 | 典型值 | 影响 | 调优建议 |
|---|---|---|---|
| `max_slope_deg` | 30-50° | 过小：漏检斜坡；过大：误检墙面 | 根据机器人爬坡能力设置 |
| `max_roughness` | 0.05-0.15m | 过小：漏检粗糙地面；过大：误检障碍 | 根据点云密度和噪声水平调整 |
| `min_planarity` | 0.6-0.8 | 过高：漏检；过低：误检 | 0.7是一个好的起点 |
| `search_radius` | 1-3× voxel_size | 过小：噪声敏感；过大：丢失细节 | 通常设为2× voxel_size |
| `cell_size` | 0.5-1.5× voxel_size | 影响高程图分辨率 | 与voxel_size保持一致 |
| `min_area` | 0.3-1.0 m² | 过小：保留小表面；过大：漏检 | 根据机器人尺寸设置 |

### 不同场景的推荐配置

#### 室内场景（办公室、走廊）
```yaml
max_slope_deg: 30.0
max_roughness: 0.08
min_planarity: 0.75
min_area: 0.3
```

#### 室外场景（草地、碎石路）
```yaml
max_slope_deg: 45.0
max_roughness: 0.15
min_planarity: 0.60
min_area: 0.5
```

#### 工业场景（仓库、工厂）
```yaml
max_slope_deg: 35.0
max_roughness: 0.10
min_planarity: 0.70
min_area: 0.4
```

---

## 参考文献

### 综述论文
1. Papadakis, P. (2013). "Terrain traversability analysis methods for unmanned ground vehicles: A survey". *Engineering Applications of Artificial Intelligence*, 26(4), 1373-1385.

2. Borges, P., et al. (2015). "A survey on terrain traversability analysis for autonomous ground vehicles: Machine learning, geometric, and visual methods". *Unmanned Systems*, 3(02), 125-146.

### 几何方法
3. Weinmann, M., et al. (2015). "Semantic point cloud interpretation based on optimal neighborhoods, relevant features and efficient classifiers". *ISPRS Journal of Photogrammetry and Remote Sensing*, 105, 286-304.

4. Schnabel, R., et al. (2007). "Efficient RANSAC for point-cloud shape detection". *Computer Graphics Forum*, 26(2), 214-226.

### 高程图方法
5. Fankhauser, P., & Hutter, M. (2018). "A Universal Grid Map Library: Implementation and Use Case for Rough Terrain Navigation". *Robot Operating System (ROS)*, 99-120.

6. Fankhauser, P., et al. (2018). "Probabilistic terrain mapping for mobile robots with uncertain localization". *IEEE Robotics and Automation Letters*, 3(4), 3019-3026.

### 机器学习方法
7. Qi, C. R., et al. (2017). "PointNet++: Deep hierarchical feature learning on point sets in a metric space". *NeurIPS*.

8. Wellhausen, L., et al. (2019). "Where should I walk? Predicting terrain properties from images via self-supervised learning". *IEEE Robotics and Automation Letters*, 4(2), 1509-1516.

### 开源实现
- **ANYbotics elevation_mapping**: https://github.com/ANYbotics/elevation_mapping
- **grid_map**: https://github.com/ANYbotics/grid_map
- **Open3D**: http://www.open3d.org/
- **PCL (Point Cloud Library)**: https://pointclouds.org/

---

## 总结

当前实现使用的方法（法向量角度 + 高度过滤 + 连通性）是一个合理的起点，但存在以下问题：

1. **参数配置错误**导致连通性算法失效（已修复）
2. **缺乏粗糙度和平面性检测**，容易误检
3. **连通性算法设计不够鲁棒**

**推荐的改进路径**：
1. 短期：修复参数 + 添加粗糙度检测
2. 中期：实现增强的几何特征方法（PCA + 多特征融合）
3. 长期：实现混合方法（局部特征 + 高程图 + 连通性）

这些方法都有学术文献支持，并在实际机器人系统中得到验证（ANYmal、Boston Dynamics等）。

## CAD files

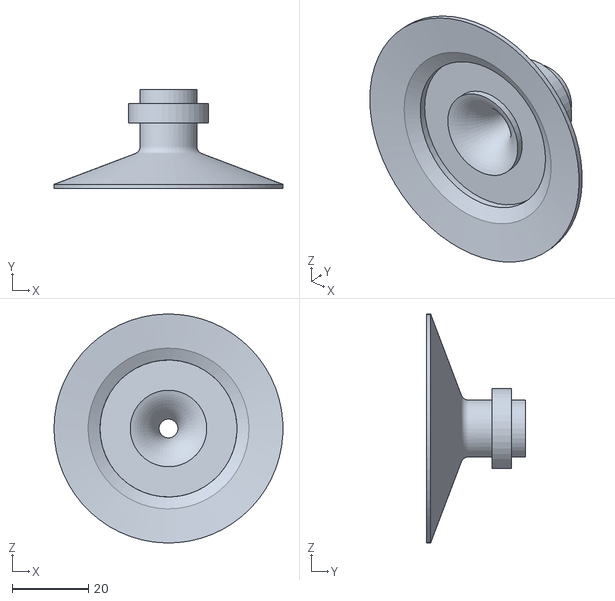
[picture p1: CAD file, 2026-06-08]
cad/DMS_sucker/DMS Sucker - Main body.STL
59.9 x 26.0 x 59.9

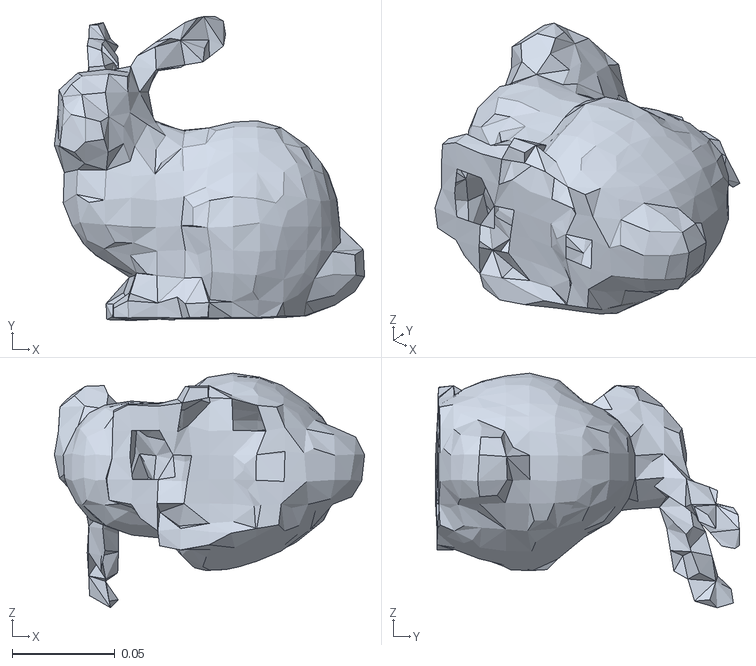
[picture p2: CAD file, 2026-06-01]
algorithms/mw_prm/datasets/bunny/reconstruction/bun_zipper_res4.ply
0.151 x 0.148 x 0.114

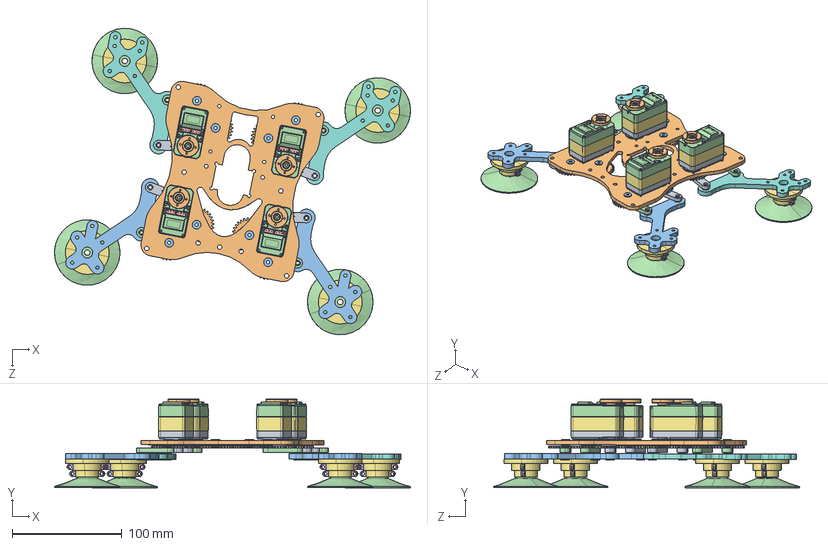
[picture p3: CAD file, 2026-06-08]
cad/Crawling System/Crawling System Layout.STEP
324.9 x 80.9 x 279.7 mm
HX-35H x 4
M2金属舵盘 x 4
底板
轴承3-6-2.5 x 32
从动杆 x 4
舵盘转接件 x 4
齿轮1-30 x 4
齿轮1-30带定位孔 x 4
垫片3-5-0.3 x 16
主动杆 x 4
齿轮1-30 沉孔_镜向默认 x 4
机臂后 x 2
Sucker x 4
吸盘连接件 x 8
机臂前· x 2

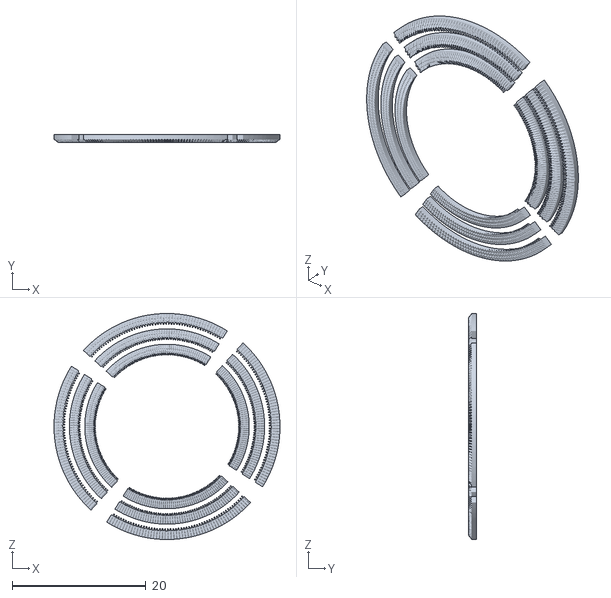
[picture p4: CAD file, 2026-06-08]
cad/DMS_sucker/DMS Sucker - Distributed micro spines.STL
33.8 x 1.19 x 33.8

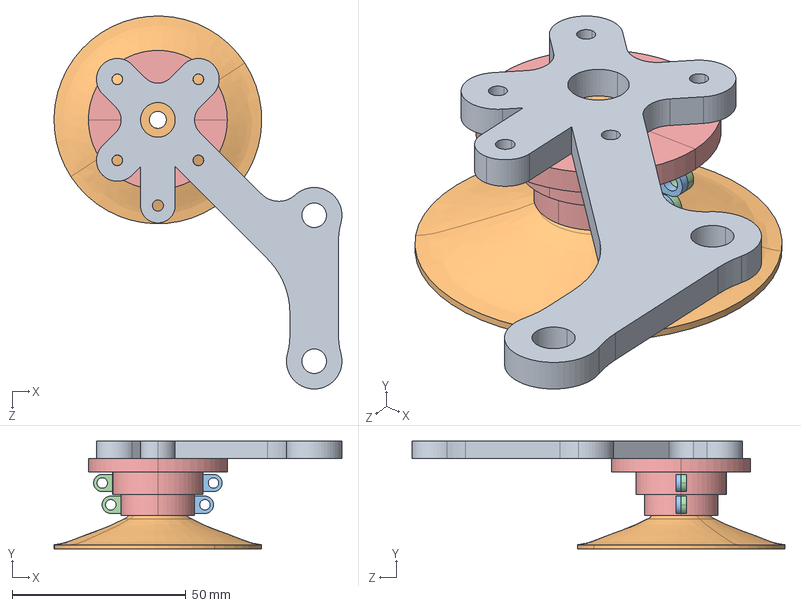
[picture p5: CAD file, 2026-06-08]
cad/Leg_Module/Hind Leg.STEP
82.9 x 31.0 x 107.4 mm
机臂后
Sucker
吸盘连接件 x 2

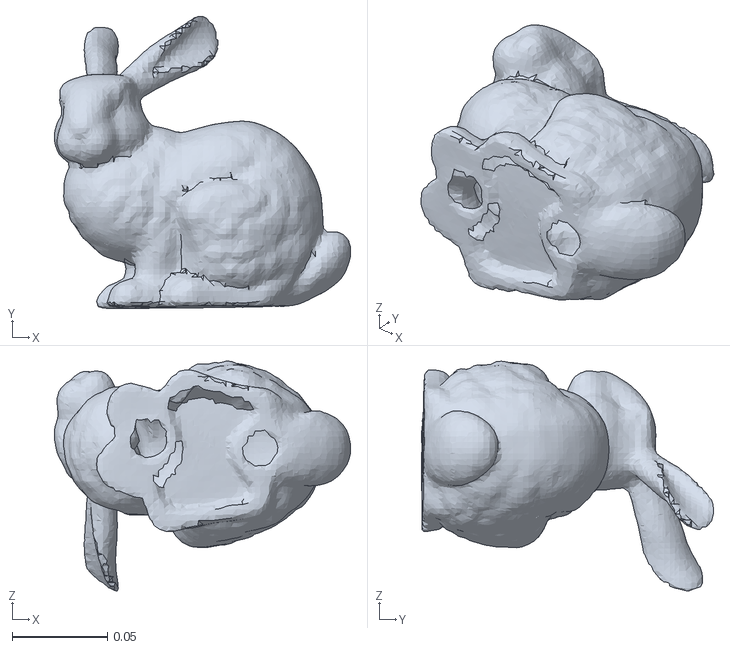
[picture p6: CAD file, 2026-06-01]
algorithms/mw_prm/datasets/bunny/reconstruction/bun_zipper_res2.ply
0.156 x 0.153 x 0.121

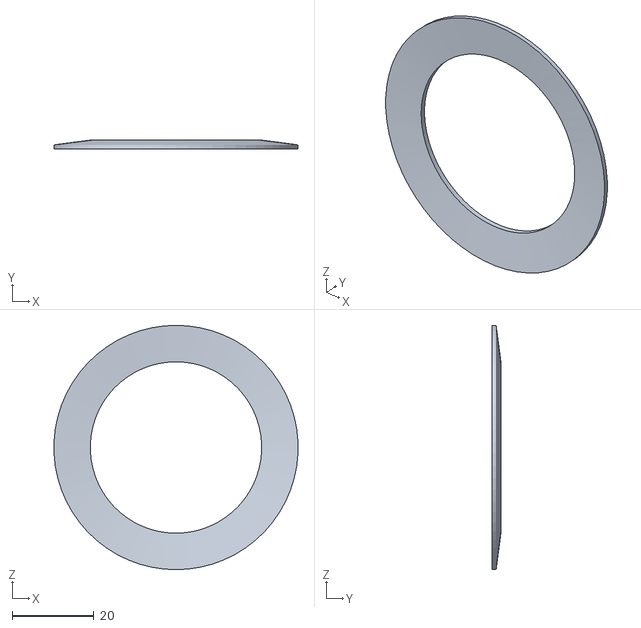
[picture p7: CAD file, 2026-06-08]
cad/DMS_sucker/DMS Sucker - Soft Lips.STL
59.8 x 2.18 x 59.9

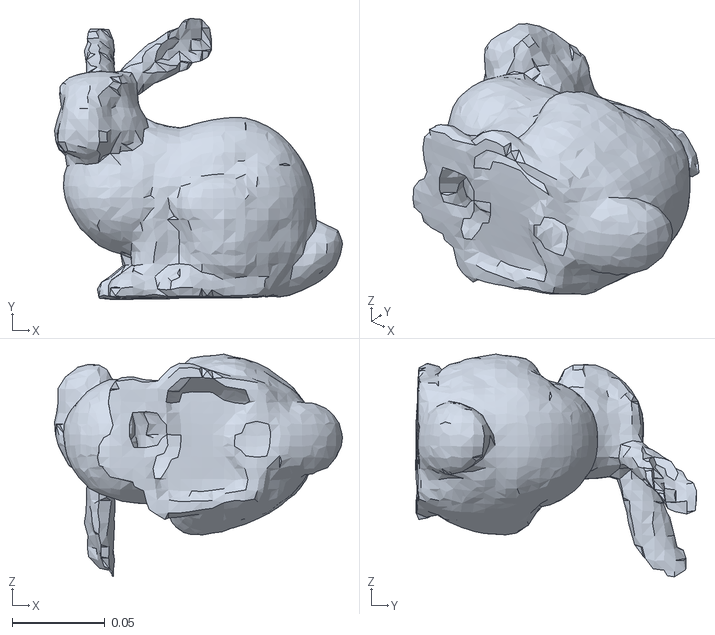
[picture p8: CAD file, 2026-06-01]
algorithms/mw_prm/datasets/bunny/reconstruction/bun_zipper_res3.ply
0.155 x 0.151 x 0.12

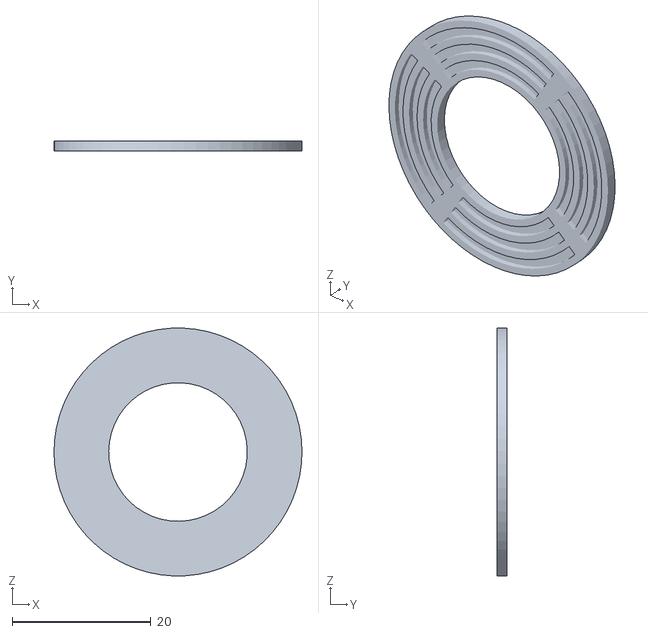
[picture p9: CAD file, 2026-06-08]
cad/DMS_sucker/DMS Sucker - Soft holder.STL
35.8 x 1.50 x 35.8

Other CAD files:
algorithms/mw_prm/datasets/bunny/data/bun270.ply
algorithms/mw_prm/datasets/bunny/data/chin.ply
cad/Leg_Module/Front Leg.STEP
algorithms/mw_prm/datasets/bunny/data/bun000.ply
algorithms/mw_prm/datasets/bunny/data/top3.ply
algorithms/mw_prm/datasets/bunny/reconstruction/bun_zipper.ply
algorithms/mw_prm/datasets/bunny/data/bun180.ply
algorithms/mw_prm/datasets/bunny/data/bun090.ply
algorithms/mw_prm/datasets/bunny/data/ear_back.ply
algorithms/mw_prm/datasets/bunny/data/bun045.ply
algorithms/mw_prm/datasets/bunny/data/bun315.ply
algorithms/mw_prm/datasets/bunny/data/top2.ply

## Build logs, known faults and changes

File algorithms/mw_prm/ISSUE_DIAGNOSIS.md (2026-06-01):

# 问题诊断：所有表面节点被过滤掉

## 问题描述

在运行 `main_pcd.py` 时，所有的可行走表面节点（surface nodes）都被过滤掉了，导致无法生成表面采样点。

## 根本原因

问题出在 `utils/env_pointcloud.py` 的 `build_environment` 函数（第724-755行）中调用的 `prune_walk_mask_by_landing_xy_extent` 函数。

### 详细分析

1. **函数目的**：`prune_walk_mask_by_landing_xy_extent` 的目的是过滤掉XY方向跨度太小的可行走表面（例如窗台、栏杆等）。

2. **算法逻辑**：
   - 将可行走点投影到 `cell_xy × cell_xy` 的网格上
   - 使用并查集找到4-连通的网格单元组
   - 对每个连通区域，计算其在X和Y方向上的跨度
   - **只保留那些 `dx_span >= min_span_xy AND dy_span >= min_span_xy` 的区域**

3. **并查集连通性**：
   ```python
   for cx, cy in buckets:
       c = (cx, cy)
       if (cx + 1, cy) in buckets:  # 只连接右边相邻的网格
           union(c, (cx + 1, cy))
       if (cx, cy + 1) in buckets:  # 只连接下边相邻的网格
           union(c, (cx, cy + 1))
   ```
   
   **关键点**：并查集只连接网格坐标差为1的相邻网格单元。

4. **问题所在**：
   
   当前配置（`yml/pcd/synth_parameters_obstacles.yml`）：
   ```yaml
   voxel: 0.3                      # 点间距约为0.3米
   walkable_min_landing_xy: 0.01   # min_span_xy = 0.01米
   walkable_cluster_cell_xy: null  # 未设置，会自动计算
   ```

   自动计算的 `cell_xy`：
   ```python
   wl = 0.01
   cell_land = max(1e-4, min(voxel_size * 0.4, wl / 14.0))
             = max(0.0001, min(0.12, 0.000714))
             = 0.000714 米
   ```

   **问题**：
   - 点间距 ≈ 0.3 米（voxel_size）
   - cell_xy = 0.000714 米
   - 相邻两点的网格坐标差 = floor(0.3 / 0.000714) ≈ 420
   
   这意味着相邻的两个点之间有419个空网格单元！并查集无法连接它们，因为它只连接网格坐标差为1的单元。

   **结果**：每个点都成为一个孤立的连通区域，其 `dx_span = dy_span = 0`，因此所有点都被过滤掉了。

## 解决方案

### 方案1：禁用过滤器（推荐用于调试）

修改 `yml/pcd/synth_parameters_obstacles.yml`：
```yaml
walkable_min_landing_xy: 0.0  # 禁用过滤器
```

**优点**：简单直接，保留所有可行走表面
**缺点**：无法过滤掉小的表面（如窗台）

### 方案2：修复参数配置

修改 `yml/pcd/synth_parameters_obstacles.yml`：
```yaml
walkable_min_landing_xy: 0.5        # 50厘米，合理的最小表面尺寸
walkable_cluster_cell_xy: 0.35      # 略大于voxel_size，确保相邻点被连接
```

**说明**：
- `cell_xy` 应该 >= `voxel_size`，以确保相邻点落在相同或相邻的网格单元中
- `min_span_xy` 应该是几十厘米到1米，以过滤掉真正的小表面

### 方案3：修改代码逻辑（需要修改源代码）

修改 `utils/env_pointcloud.py` 第745-749行的自动计算逻辑：

```python
# 原代码
wl = float(walkable_min_landing_xy)
cell_land = max(
    1e-4,
    min(float(voxel_size) * 0.4, wl / 14.0),
)

# 修改为
wl = float(walkable_min_landing_xy)
cell_land = max(
    float(voxel_size) * 0.8,  # 确保 >= voxel_size
    min(float(voxel_size) * 1.2, wl / 10.0),
)
```

**优点**：自动计算出合理的 `cell_xy` 值
**缺点**：需要修改源代码

## 参数设计原则

1. **cell_xy 的选择**：
   - 应该 >= 点间距（通常是 voxel_size）
   - 太小：破坏连通性，导致所有点被过滤
   - 太大：可能将不相邻的点错误地连接起来
   - 推荐值：`voxel_size` 到 `1.5 * voxel_size`

2. **min_span_xy 的选择**：
   - 取决于你想过滤掉多小的表面
   - 窗台、栏杆：通常 < 0.5 米
   - 桌面、平台：通常 > 0.5 米
   - 推荐值：0.5 - 1.0 米

3. **两者的关系**：
   - `cell_xy` 控制连通性判断的粒度
   - `min_span_xy` 控制过滤的阈值
   - 它们应该独立设置，不应该让 `min_span_xy` 影响 `cell_xy` 的计算

## 测试验证

修改配置后，运行：
```bash
python main_pcd.py --yml yml/pcd/synth_parameters_obstacles.yml
```

检查输出中的 `surface points` 数量是否 > 0。

## 相关代码位置

- 问题函数：[utils/env_pointcloud.py:313-392](utils/env_pointcloud.py#L313-L392) `prune_walk_mask_by_landing_xy_extent`
- 调用位置：[utils/env_pointcloud.py:740-755](utils/env_pointcloud.py#L740-L755) `build_environment`
- 参数计算：[utils/env_pointcloud.py:745-749](utils/env_pointcloud.py#L745-L749)
- 配置文件：[yml/pcd/synth_parameters_obstacles.yml:30](yml/pcd/synth_parameters_obstacles.yml#L30)

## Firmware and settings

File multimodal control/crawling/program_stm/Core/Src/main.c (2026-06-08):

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
/* Includes ------------------------------------------------------------------*/
#include "main.h"

/* USER CODE BEGIN Includes */
#include "delay.h"
#include "SMS_STS.h"
#include "robotMotion.h"

/* USER CODE END Includes */

I2C_HandleTypeDef hi2c1;
I2C_HandleTypeDef hi2c2;

SPI_HandleTypeDef hspi1;

UART_HandleTypeDef huart1;
UART_HandleTypeDef huart2;

void SystemClock_Config(void);
static void MX_GPIO_Init(void);
static void MX_I2C1_Init(void);
static void MX_I2C2_Init(void);
static void MX_SPI1_Init(void);
static void MX_USART1_UART_Init(void);
static void MX_USART2_UART_Init(void);
/* USER CODE BEGIN PFP */
int ret;

uint8_t msgUART1[8] = {0};
int8_t instruction;
int8_t param1;
float param2;

uint8_t stopFlag = 0;
/* USER CODE END PFP */

/**
  * @brief  The application entry point.
  * @retval int
  */
int main(void)
{
  /* MCU Configuration--------------------------------------------------------*/

  /* Reset of all peripherals, Initializes the Flash interface and the Systick. */
  HAL_Init();

  /* USER CODE BEGIN Init */
	delay_init(168);
  /* USER CODE END Init */

  /* Configure the system clock */
  SystemClock_Config();

  /* Initialize all configured peripherals */
  MX_GPIO_Init();
  MX_I2C1_Init();
  MX_I2C2_Init();
  MX_SPI1_Init();
  MX_USART1_UART_Init();
  MX_USART2_UART_Init();
  /* USER CODE BEGIN 2 */
	WritePosEx(1, 2048, 1200, 50);
	WritePosEx(2, 2048, 1200, 50);
	WritePosEx(3, 2048, 1200, 50);
	WritePosEx(4, 2048, 1200, 50);
	delay_ms(500);
	
	HAL_UART_Receive_IT(&huart1, msgUART1, 8);
  /* USER CODE END 2 */

  /* Infinite loop */
  /* USER CODE BEGIN WHILE */
  while (1)
  {
    /* USER CODE END WHILE */
		
		//param1 refers to which side to step first
		//param2 refers to the division
		if(instruction){
			switch(instruction){
				case -1:
					robotOneStepBackward(param1, param2);
					break;
				case 1:
					robotOneStepForward(param1, param2);
					break;
				case 2:
					robotOneStepLeft(param2);
					break;
				case 3:
					robotOneStepRight(param2);
					break;
				
				case 8:
					stopFlag = 0;
					robotContinuousForward(param1, param2, &stopFlag);
					break;
				case 9:
					stopFlag = 1;
					break;
			}
			instruction = 0;
		}
		
    /* USER CODE BEGIN 3 */
  }
  /* USER CODE END 3 */
}

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
/* USER CODE BEGIN 4 */

void HAL_UART_RxCpltCallback(UART_HandleTypeDef *huart)
{
	uint8_t Pin_State;
	static uint8_t LED_Pin_State = 0;
  if(huart->Instance == USART1){
		switch(msgUART1[0]){
			case 0x01:
				//LED instruction
				LED_Pin_State = ~LED_Pin_State;
				HAL_GPIO_WritePin(GPIOB, LED_Pin, LED_Pin_State);
				break;
			case 0x02:
				//Solenoid valve instruction
				Pin_State = HAL_GPIO_ReadPin(GPIOB, Solenoid1_Pin << (msgUART1[1] - 1));
				HAL_GPIO_WritePin(GPIOB, Solenoid1_Pin << (msgUART1[1] - 1), 1 - Pin_State);
				break;
			case 0x03:
				Pin_State = HAL_GPIO_ReadPin(GPIOB, Pump_PWM_Pin);
				HAL_GPIO_WritePin(GPIOB, Pump_PWM_Pin, 1 - Pin_State);
				
				break;
			case 0x7F:  
				//Servo instruction
				instruction = *(int8_t*)(msgUART1 + 1);  //1 = forward, 2 = left, 3 = right, -1 = backward, 8 = continuous, 9 = stop continuous
			  if (instruction == 9){
					stopFlag = 1;
				}
				param1 = *(int8_t*)(msgUART1 + 2);  //parameter 1
				param2 = *(float*)(msgUART1 + 4);  //parameter 2
				break;
		}
		HAL_UART_Receive_IT(&huart1, msgUART1, 8);
	}
}
	
void Uart_Send(uint8_t *buf , uint16_t len)
{
	HAL_UART_Transmit(&huart2, buf, len, HAL_MAX_DELAY);
}

int16_t Uart_Read(uint8_t *buf , uint16_t len, uint32_t timeout)
{
	if(HAL_UART_Receive(&huart2, buf, len, timeout)==HAL_OK){
		return len;
	}else{
		return 0;
	}
}


/* USER CODE END 4 */
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


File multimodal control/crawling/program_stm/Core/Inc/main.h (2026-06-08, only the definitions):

#define Servo_UART_TX_Pin GPIO_PIN_2
#define Servo_UART_TX_GPIO_Port GPIOA
#define Servo_UART_RX_Pin GPIO_PIN_3
#define Servo_UART_RX_GPIO_Port GPIOA
#define LED_Pin GPIO_PIN_0
#define LED_GPIO_Port GPIOB
#define Solenoid1_Pin GPIO_PIN_12
#define Solenoid1_GPIO_Port GPIOB
#define Solenoid2_Pin GPIO_PIN_13
#define Solenoid2_GPIO_Port GPIOB
#define Solenoid3_Pin GPIO_PIN_14
#define Solenoid3_GPIO_Port GPIOB
#define Solenoid4_Pin GPIO_PIN_15
#define Solenoid4_GPIO_Port GPIOB
#define MPU_SCL_Pin GPIO_PIN_6
#define MPU_SCL_GPIO_Port GPIOB
#define MPU_SDA_Pin GPIO_PIN_7
#define MPU_SDA_GPIO_Port GPIOB
#define Pump_PWM_Pin GPIO_PIN_9
#define Pump_PWM_GPIO_Port GPIOB

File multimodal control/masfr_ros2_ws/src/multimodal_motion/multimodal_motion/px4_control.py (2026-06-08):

#!/usr/bin/env python3

import rclpy
import serial
import struct
import time
import numpy as np
from rclpy.node import Node
from rclpy.qos import QoSProfile, ReliabilityPolicy, HistoryPolicy, DurabilityPolicy
from std_msgs.msg import Int16, Float32MultiArray, Bool
from px4_msgs.msg import OffboardControlMode, TrajectorySetpoint, VehicleCommand, VehicleLocalPosition, VehicleStatus
from nav_msgs.msg import Path

from scipy.spatial.transform import Rotation as R


class OffboardControl(Node):
    """Node for controlling a vehicle in offboard mode."""

    def __init__(self) -> None:
        super().__init__('offboard_control_takeoff_and_land')

        # Configure QoS profile for publishing and subscribing
        qos_profile = QoSProfile(
            reliability=ReliabilityPolicy.BEST_EFFORT,
            durability=DurabilityPolicy.TRANSIENT_LOCAL,
            history=HistoryPolicy.KEEP_LAST,
            depth=1024
        )

        # Create publishers
        self.offboard_control_mode_publisher = self.create_publisher(
            OffboardControlMode, '/fmu/in/offboard_control_mode', 10)
        self.trajectory_setpoint_publisher = self.create_publisher(
            TrajectorySetpoint, '/fmu/in/trajectory_setpoint', qos_profile)
        self.vehicle_command_publisher = self.create_publisher(
            VehicleCommand, '/fmu/in/vehicle_command', qos_profile)

        # Create px4 subscribers
        self.vehicle_local_position_subscriber = self.create_subscription(
            VehicleLocalPosition, '/fmu/out/vehicle_local_position', self.vehicle_local_position_callback, qos_profile)
        self.vehicle_status_subscriber = self.create_subscription(
            VehicleStatus, '/fmu/out/vehicle_status', self.vehicle_status_callback, qos_profile)
        
        # Create robot subscribers
        self.fly_path_subscriber = self.create_subscription(Float32MultiArray, '/target_fly_path', self.fly_path_callback, 10)
        self.kill_all_subscriber = self.create_subscription(Bool, '/kill_all', self.kill_all_callback, 10)
        # send True signal to the topic to inform the manipulator node the flying state terminates 
        self.fly_final_publisher = self.create_publisher(Bool, '/fly_terminate', 10)

        # Initialize variables
        self.vehicle_local_position = VehicleLocalPosition()
        self.vehicle_status = VehicleStatus()

        self.target_fly_path = []
        self.begin = False
        self.is_taken_off = False

        self.mainloop_counter = 0

        # Create a timer to publish control commands
        self.timer = self.create_timer(0.1, self.timer_callback)
        self.timer_mainloop = self.create_timer(1, self.mainloop)


        self.serRobot = serial.Serial('/dev/ttyAMA2', 115200)
        if self.serRobot.is_open == False:
            self.serRobot.open()

    def vehicle_local_position_callback(self, vehicle_local_position):
        """Callback function for vehicle_local_position topic subscriber."""
        self.vehicle_local_position = vehicle_local_position

    def vehicle_status_callback(self, vehicle_status):
        """Callback function for vehicle_status topic subscriber."""
        self.vehicle_status = vehicle_status
    
    def robot_state_callback(self, robot_status):
        self.robot_status = robot_status

    def fly_path_callback(self, msg):

        rows = msg.layout.dim[0].size
        cols = msg.layout.dim[1].size

        points = []
        for i in range(rows):
            row = msg.data[i * cols: (i + 1) * cols]
            row = np.asarray(row)
            row = row / 10
            points.append(row.tolist())
    
        self.target_fly_path = points
        print(self.target_fly_path)
        self.begin = True

    def kill_all_callback(self, msg):
        if msg:
            exit(0)

    def arm(self):
        """Send an arm command to the vehicle."""
        self.publish_vehicle_command(
            VehicleCommand.VEHICLE_CMD_COMPONENT_ARM_DISARM, param1=1.0)

    def takeoff(self):
        for i in range(50):
            print('Arming the vehicle')
            self.flight_termination(0.0)
            self.arm()
            time.sleep(0.1)
            

    def disarm(self):
        """Send a disarm command to the vehicle."""
        self.publish_vehicle_command(
            VehicleCommand.VEHICLE_CMD_COMPONENT_ARM_DISARM, param1=0.0)
        self.get_logger().info('Disarm command sent')

    def flight_termination(self, param1):
        """Send a disarm command to the vehicle."""
        self.publish_vehicle_command(
            VehicleCommand.VEHICLE_CMD_DO_FLIGHTTERMINATION, param1=param1)
        self.get_logger().info('kill command sent')

    def engage_offboard_mode(self):
        """Switch to offboard mode."""
        self.publish_vehicle_command(
            VehicleCommand.VEHICLE_CMD_DO_SET_MODE, param1=1.0, param2=6.0)
        self.get_logger().info("Switching to offboard mode")

    def engage_position_mode(self):
        """Switch to offboard mode."""
        self.publish_vehicle_command(
            VehicleCommand.VEHICLE_CMD_DO_SET_MODE, param1=1.0, param2=3.0)
        self.get_logger().info("Switching to position mode")

    def engage_height_mode(self):
        """Switch to offboard mode."""
        self.publish_vehicle_command(
            VehicleCommand.VEHICLE_CMD_DO_SET_MODE, param1=1.0, param2=2.0)
        self.get_logger().info("Switching to height mode")

    def land(self):
        """Switch to land mode."""
        self.publish_vehicle_command(VehicleCommand.VEHICLE_CMD_NAV_LAND)
        self.get_logger().info("Switching to land mode")

    def publish_offboard_control_heartbeat_signal(self):
        """Publish the offboard control mode."""
        msg = OffboardControlMode()
        msg.position = True
        msg.velocity = False
        msg.acceleration = False
        msg.attitude = False
        msg.body_rate = False
        msg.timestamp = int(self.get_clock().now().nanoseconds / 1000)
        self.offboard_control_mode_publisher.publish(msg)

    def publish_position_setpoint(self, x: float, y: float, z: float, yaw: float):
        """Publish the trajectory setpoint."""
        msg = TrajectorySetpoint()
        msg.position = [x, y, z]
        msg.yaw = yaw
        msg.timestamp = int(self.get_clock().now().nanoseconds / 1000)
        self.trajectory_setpoint_publisher.publish(msg)
        self.get_logger().info(f"Publishing position setpoints {[x, y, z]}")
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

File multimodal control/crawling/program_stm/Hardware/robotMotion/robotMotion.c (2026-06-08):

#include "robotMotion.h"

void robotContinuousForward(int8_t firstSide, float division, uint8_t* stopFlag){  //firstSide = 1 for left, firstSide = -1 for right, division < 1
	
	while(*stopFlag == 0){
		//STAGE 1
		if(firstSide == -1){
			HAL_GPIO_WritePin(GPIOB, Solenoid1_Pin, GPIO_PIN_SET);
			HAL_GPIO_WritePin(GPIOB, Solenoid2_Pin, GPIO_PIN_SET);
			HAL_GPIO_WritePin(GPIOB, Solenoid3_Pin, GPIO_PIN_RESET);
			HAL_GPIO_WritePin(GPIOB, Solenoid4_Pin, GPIO_PIN_RESET);
		}else if(firstSide == 1){
			HAL_GPIO_WritePin(GPIOB, Solenoid1_Pin, GPIO_PIN_RESET);
			HAL_GPIO_WritePin(GPIOB, Solenoid2_Pin, GPIO_PIN_RESET);
			HAL_GPIO_WritePin(GPIOB, Solenoid3_Pin, GPIO_PIN_SET);
			HAL_GPIO_WritePin(GPIOB, Solenoid4_Pin, GPIO_PIN_SET);
		}
		
		delay_ms(500);
		
		int16_t control1 = 2048. - 1024. * division * firstSide;
		WritePosEx(1, control1, 1200, 50);
		WritePosEx(2, control1, 1200, 50);
		WritePosEx(3, control1, 1200, 50);
		WritePosEx(4, control1, 1200, 50);
		
		delay_ms((uint16_t)(2000. * division));
		
		//STAGE 2
		if(firstSide == -1){
			HAL_GPIO_WritePin(GPIOB, Solenoid1_Pin, GPIO_PIN_RESET);
			HAL_GPIO_WritePin(GPIOB, Solenoid2_Pin, GPIO_PIN_RESET);
			HAL_GPIO_WritePin(GPIOB, Solenoid3_Pin, GPIO_PIN_SET);
			HAL_GPIO_WritePin(GPIOB, Solenoid4_Pin, GPIO_PIN_SET);
		}else if(firstSide == 1){
			HAL_GPIO_WritePin(GPIOB, Solenoid1_Pin, GPIO_PIN_SET);
			HAL_GPIO_WritePin(GPIOB, Solenoid2_Pin, GPIO_PIN_SET);
			HAL_GPIO_WritePin(GPIOB, Solenoid3_Pin, GPIO_PIN_RESET);
			HAL_GPIO_WritePin(GPIOB, Solenoid4_Pin, GPIO_PIN_RESET);
		}
		
		delay_ms(500);
		
		int16_t control2 = 2048. + 1024. * division * firstSide;
		WritePosEx(1, control2, 1200, 50);
		WritePosEx(2, control2, 1200, 50);
		WritePosEx(3, control2, 1200, 50);
		WritePosEx(4, control2, 1200, 50);
		
		delay_ms((uint16_t)(2000. * division));
	}
	
	//STAGE 3
	if(firstSide == -1){
		HAL_GPIO_WritePin(GPIOB, Solenoid1_Pin, GPIO_PIN_SET);
		HAL_GPIO_WritePin(GPIOB, Solenoid2_Pin, GPIO_PIN_SET);
		HAL_GPIO_WritePin(GPIOB, Solenoid3_Pin, GPIO_PIN_RESET);
		HAL_GPIO_WritePin(GPIOB, Solenoid4_Pin, GPIO_PIN_RESET);
	}else if(firstSide == 1){
		HAL_GPIO_WritePin(GPIOB, Solenoid1_Pin, GPIO_PIN_RESET);
		HAL_GPIO_WritePin(GPIOB, Solenoid2_Pin, GPIO_PIN_RESET);
		HAL_GPIO_WritePin(GPIOB, Solenoid3_Pin, GPIO_PIN_SET);
		HAL_GPIO_WritePin(GPIOB, Solenoid4_Pin, GPIO_PIN_SET);
	}
	
	delay_ms(500);
	
	WritePosEx(1, 2048, 1200, 50);
	WritePosEx(2, 2048, 1200, 50);
	WritePosEx(3, 2048, 1200, 50);
	WritePosEx(4, 2048, 1200, 50);
	
	delay_ms((uint16_t)(1000. * division));
	
}

void robotOneStepForward(int8_t firstSide, float division){  //firstSide = 1 for left, firstSide = -1 for right, division < 1
	
	//STAGE 1
	if(firstSide == -1){
		HAL_GPIO_WritePin(GPIOB, Solenoid1_Pin, GPIO_PIN_SET);
		HAL_GPIO_WritePin(GPIOB, Solenoid2_Pin, GPIO_PIN_SET);
		HAL_GPIO_WritePin(GPIOB, Solenoid3_Pin, GPIO_PIN_RESET);
		HAL_GPIO_WritePin(GPIOB, Solenoid4_Pin, GPIO_PIN_RESET);
	}else if(firstSide == 1){
		HAL_GPIO_WritePin(GPIOB, Solenoid1_Pin, GPIO_PIN_RESET);
		HAL_GPIO_WritePin(GPIOB, Solenoid2_Pin, GPIO_PIN_RESET);
		HAL_GPIO_WritePin(GPIOB, Solenoid3_Pin, GPIO_PIN_SET);
		HAL_GPIO_WritePin(GPIOB, Solenoid4_Pin, GPIO_PIN_SET);
	}
	
	delay_ms(500);
	
	int16_t control1 = 2048. - 1024. * division * firstSide;
	WritePosEx(1, control1, 1200, 50);
	WritePosEx(2, control1, 1200, 50);
	WritePosEx(3, control1, 1200, 50);
	WritePosEx(4, control1, 1200, 50);
	
	delay_ms((uint16_t)(2000. * division));
	
	//STAGE 2
	if(firstSide == -1){
		HAL_GPIO_WritePin(GPIOB, Solenoid1_Pin, GPIO_PIN_RESET);
		HAL_GPIO_WritePin(GPIOB, Solenoid2_Pin, GPIO_PIN_RESET);
		HAL_GPIO_WritePin(GPIOB, Solenoid3_Pin, GPIO_PIN_SET);
		HAL_GPIO_WritePin(GPIOB, Solenoid4_Pin, GPIO_PIN_SET);
	}else if(firstSide == 1){
		HAL_GPIO_WritePin(GPIOB, Solenoid1_Pin, GPIO_PIN_SET);
		HAL_GPIO_WritePin(GPIOB, Solenoid2_Pin, GPIO_PIN_SET);
		HAL_GPIO_WritePin(GPIOB, Solenoid3_Pin, GPIO_PIN_RESET);
		HAL_GPIO_WritePin(GPIOB, Solenoid4_Pin, GPIO_PIN_RESET);
	}
	
	delay_ms(500);
	
	int16_t control2 = 2048. + 1024. * division * firstSide;
	WritePosEx(1, control2, 1200, 50);
	WritePosEx(2, control2, 1200, 50);
	WritePosEx(3, control2, 1200, 50);
	WritePosEx(4, control2, 1200, 50);
	
	delay_ms((uint16_t)(2000. * division));
	
	//STAGE 3
	if(firstSide == -1){
		HAL_GPIO_WritePin(GPIOB, Solenoid1_Pin, GPIO_PIN_SET);
		HAL_GPIO_WritePin(GPIOB, Solenoid2_Pin, GPIO_PIN_SET);
		HAL_GPIO_WritePin(GPIOB, Solenoid3_Pin, GPIO_PIN_RESET);
		HAL_GPIO_WritePin(GPIOB, Solenoid4_Pin, GPIO_PIN_RESET);
	}else if(firstSide == 1){
		HAL_GPIO_WritePin(GPIOB, Solenoid1_Pin, GPIO_PIN_RESET);
		HAL_GPIO_WritePin(GPIOB, Solenoid2_Pin, GPIO_PIN_RESET);
		HAL_GPIO_WritePin(GPIOB, Solenoid3_Pin, GPIO_PIN_SET);
		HAL_GPIO_WritePin(GPIOB, Solenoid4_Pin, GPIO_PIN_SET);
	}
	
	delay_ms(500);
	
	WritePosEx(1, 2048, 1200, 50);
	WritePosEx(2, 2048, 1200, 50);
	WritePosEx(3, 2048, 1200, 50);
	WritePosEx(4, 2048, 1200, 50);
	
	delay_ms((uint16_t)(1000. * division));
}
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

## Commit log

2026-06-01 Add MW-PRM algorithm module and replication README
    [bun000.ply, bun045.ply, bun090.ply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]
2026-06-08 Organize MASFR project materials
    [Crawling System Layout.STEP, DMS Sucker - Distributed micro spines.STL, DMS Sucker - Main body.STL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]

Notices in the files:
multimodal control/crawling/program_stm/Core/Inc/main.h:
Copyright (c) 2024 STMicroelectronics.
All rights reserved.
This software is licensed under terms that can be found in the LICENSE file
